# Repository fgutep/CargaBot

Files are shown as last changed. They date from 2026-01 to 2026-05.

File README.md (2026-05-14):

# CargaBot - Open Source ROS2 Forklift Platform

> **This is an active development project** - Originally started as a TurtleBot Burger clone, this project has evolved into a four-level forklift (montacargas) robot designed for object classification and manipulation.

An open-source, differential drive forklift robot designed to identify, pick up, and classify colored cubes (green, red, blue) using computer vision. By transitioning from a standard mobile base to a forklift architecture, CargaBot provides superior mechanical stability and simplified vertical positioning compared to traditional multi-degree-of-freedom robotic arms.

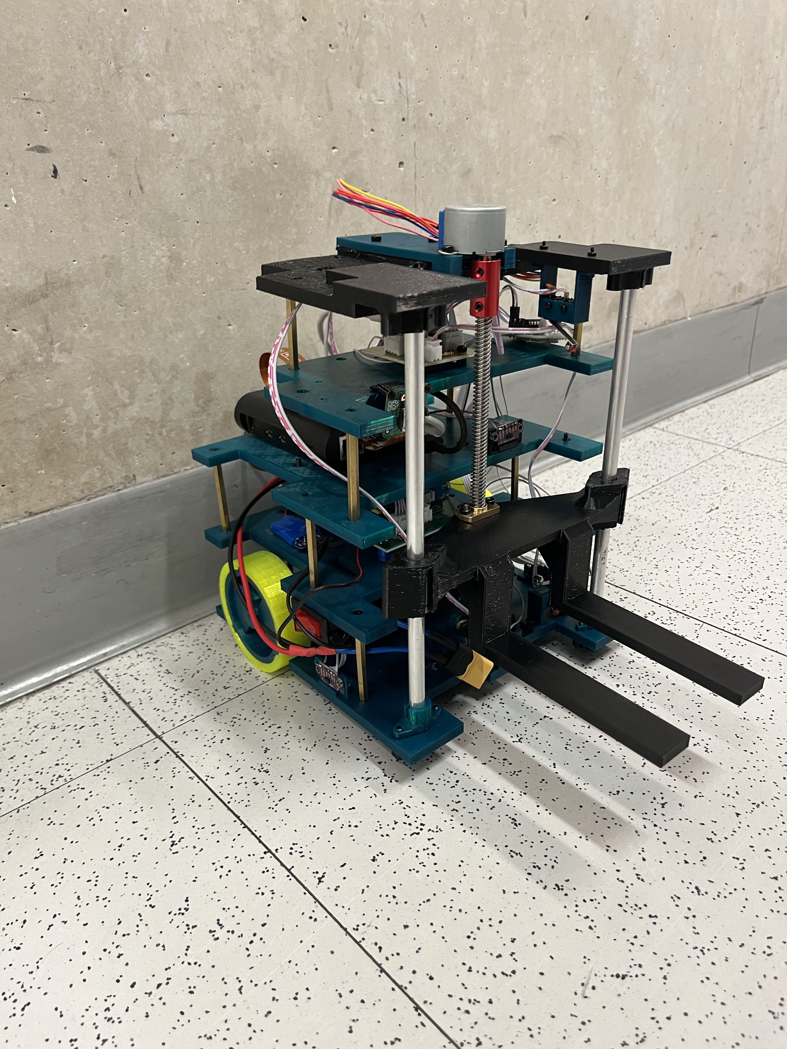
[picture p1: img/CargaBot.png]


## Project Goals

- **Accessible**: Built using affordable components like the Raspberry Pi 5, ESP32 microcontrollers, and fully 3D-printable parts.
- **Educational**: A hands-on platform for learning ROS2, computer vision (YOLOv8), embedded systems, and robot kinematics.
- **Object Manipulation**: Features a custom-built elevator mechanism specifically designed for picking up and stacking objects in a laboratory environment.
- **Distributed Processing**: Utilizes remote PC processing for heavy computer vision tasks to maintain real-time operational efficiency on the robot itself.

## Bill of Materials

### Electronics
- **Main Computer**: Raspberry Pi 5 (8GB) - Serves as the primary system processor and runs the ROS2 middleware.
- **Motion Controller**: ESP32-S3 (Dual-core, 240 MHz) - Manages the wheel odometry and traction bridge.
- **Lift & Sensor Controller**: Custom Waveshare ESP32-S3 Zero PCB - Handles $I^{2}C$ multiplexing and elevator control signals.
- **Sensors**: 5x VL53L0X Time-of-Flight sensors - Four provide lateral obstacle avoidance, while the fifth measures the elevator's height.
- **Vision**: Raspberry Pi Camera Module (5 MP, CSI interface) - Oriented downward to capture objects for the vision model.
- **Motors (Traction)**: 2x DC motors with integrated encoders for precise odometry.
- **Motor (Lift)**: 5V Stepper motor for driving the vertical elevator mechanism.
- **Drivers**: Two DRV8833 drivers (configured in parallel to handle higher current) for traction, and a dedicated 5V stepper driver for the lift.

### Mechanical
- **Chassis**: Custom 4-level 3D-printed PLA structure connected by structural support rods for dynamic rigidity.
- **Elevator System**: Driven by a T8 4-start lead screw, supported by upper and lower mechanical limit switches (end-stops) for safe positioning.
- **Wheels**: Custom PLA-printed wheels equipped with TPU treads to significantly improve traction and reduce slipping.

## Key Features & Architecture

### Hardware: The 4-Level Design
- **Level 1 (Base)**: Houses the traction motors, the TPU-treaded wheels, and four VL53L0X ToF sensors pointing forward, backward, left, and right for obstacle avoidance.
- **Level 2 (Electronic Control)**: Contains the main ESP32-S3 board, the parallel DRV8833 motor drivers, and decoupling capacitors.
- **Level 3 (Computation)**: Holds the Raspberry Pi 5 and a vertically positioned fifth VL53L0X sensor used to continuously track the elevator's height without signal interference.
- **Level 4 (Elevator System)**: Accommodates the Pi Camera, the 5V stepper motor driver, and the custom Waveshare ESP32-S3 Zero PCB used for the $I^{2}C$ multiplexing.

### Software
- **ROS2 Middleware**: Relies on a full ROS2 communication suite managing synchronized, distributed nodes.
- **Dual Serial Bridges**: Operates two independent communication bridges; one dedicated to wheel odometry/positioning, and a new "Zero" bridge for exposing the five ToF sensors and the lift state.
- **Distributed YOLOv8 Vision**: Local YOLOv8 inference saturated the Raspberry Pi 5 CPU (reaching 97%), making it impossible to run other nodes simultaneously. To solve this, video is streamed continuously via GStreamer (RTSP protocol) to a desktop computer. The PC runs the YOLOv8 model in real-time and publishes the detection results (class, confidence, and coordinates) back to the robot via ROS2 messages.

## Known Issues & Future Improvements

- **Lift Speed**: The current 5V stepper motor provides precision but is very slow, taking approximately 90 seconds to elevate the platform 15 cm. A planned improvement is to replace this with a more powerful DC motor coupled with gears.
- **Low-Speed PID Control**: The traction PID control has a sensitive minimum PWM threshold and behaves abruptly at low speeds. Upgrading to higher-capacity drivers and further tuning is planned for future iterations.
- **Vision Latency**: While running inference on the PC's GPU is highly efficient, the RTSP video transmission introduces around 200 ms of latency. Future optimizations will explore video compression and hardware acceleration on the Pi 5 to reduce this delay.

## Repository Structure
*(Structure is currently being reorganized to accommodate the new dual-firmware and 4-level chassis files)*

## Getting Started
### Prerequisites
- 3D printer (PLA for chassis components, TPU for wheel treads).
- ROS2 installation (Humble recommended).
- A remote PC with a dedicated GPU for YOLOv8 processing.

*Detailed wiring and build instructions for the 4-level chassis coming soon!*

## Contributing
We welcome contributions! Please open an issue or pull request if you'd like to contribute.

## License
This project is open-source and available under the [MIT License](LICENSE).

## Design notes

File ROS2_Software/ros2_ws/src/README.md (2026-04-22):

# TurtleBot ROS2 Lab 1

Proyecto de control y seguimiento de trayectoria de TurtleBot usando ROS2 Humble.

## Descripción

Este proyecto implementa tres nodos de ROS2:
- **turtle_bot_teleop**: Control manual del robot mediante teclado (WASD)
- **turtle_bot_interface**: Interfaz gráfica para visualizar trayectoria y gestionar grabaciones
- **turtle_bot_player**: Reproducción de trayectorias grabadas

## Requisitos

- ROS2 Humble  (pues a la maldita sea con jazzy tambien)
- Python 3.10+
- CoppeliaSim (para simulación)
- Librerías: matplotlib, tkinter

## Instalación
```bash
# Clonar el repositorio
cd ~/ros2_ws/src
git clone https://github.com/TU_USUARIO/turtlebot-ros2-lab1.git

# Instalar dependencias
pip3 install matplotlib --break-system-packages
sudo apt install python3-tk

# Compilar
cd ~/ros2_ws
colcon build
source install/setup.bash
```

## Uso

### Terminal 1: Interfaz gráfica
```bash
ros2 run lab1_py_pkg turtle_bot_interface
```

### Terminal 2: Control por teclado
```bash
ros2 run lab1_py_pkg turtle_bot_teleop
```

### Terminal 3: Reproductor (opcional)
```bash
ros2 run lab1_py_pkg turtle_bot_player
```

## Estructura del Proyecto
```
turtlebot_lab1_project/
├── lab1_msgs/              # Mensajes y servicios personalizados
│   ├── msg/
│   │   └── RobotAction.msg
│   └── srv/
│       └── PlayRecording.srv
└── lab1_py_pkg/            # Nodos de Python
    ├── turtle_bot_teleop.py
    ├── turtle_bot_interface.py
    └── turtle_bot_player.py
```

## Características

- ✅ Control del robot con WASD
- ✅ Visualización de trayectoria en tiempo real
- ✅ Grabación de secuencia de acciones
- ✅ Reproducción de trayectorias grabadas
- ✅ Exportación de gráficas (PNG, PDF, SVG)
- ✅ Mensajes y servicios personalizados

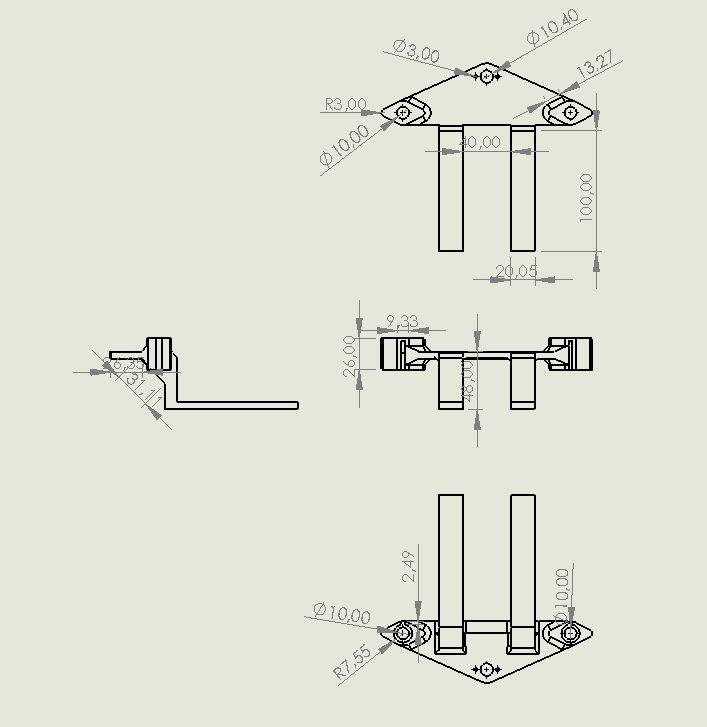
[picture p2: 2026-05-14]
CAD/PLANOS/Plano_soporte_elevador.png

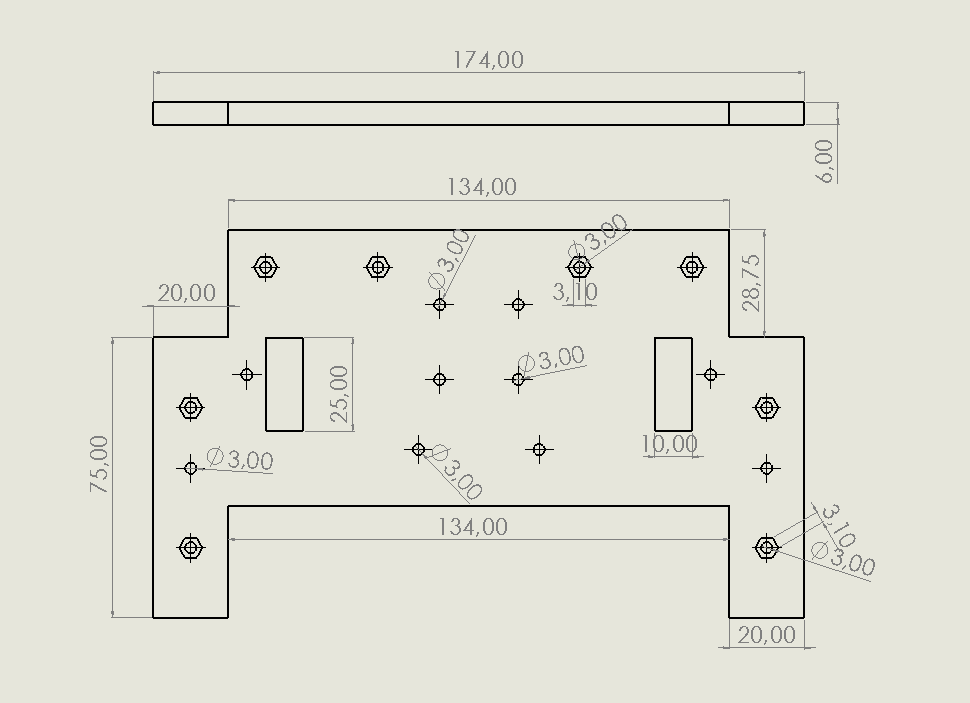
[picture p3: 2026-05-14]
CAD/PLANOS/Plano_piso4.png

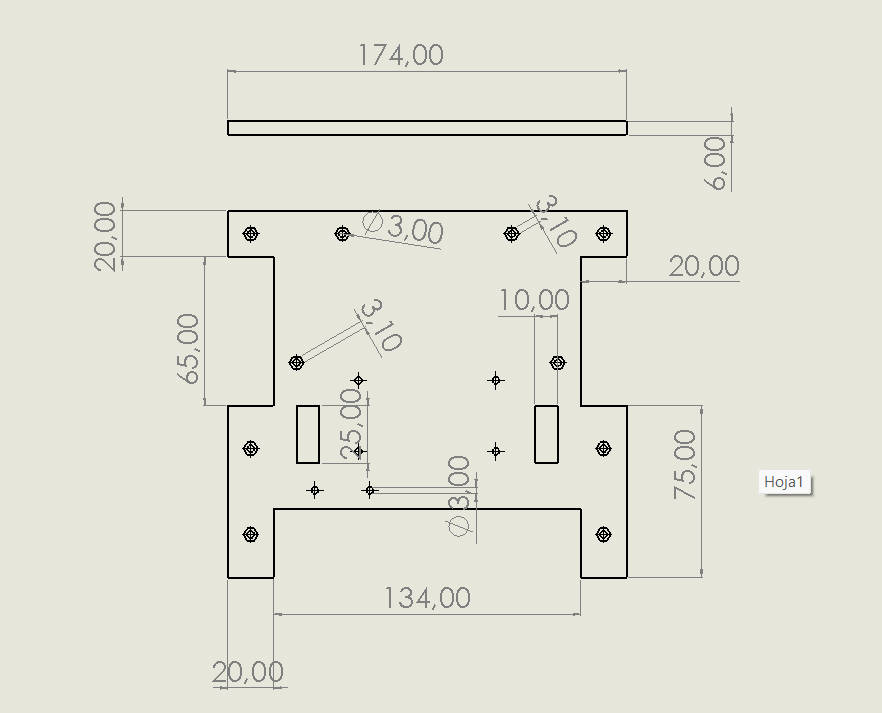
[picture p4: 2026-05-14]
CAD/PLANOS/Plano_piso2.png

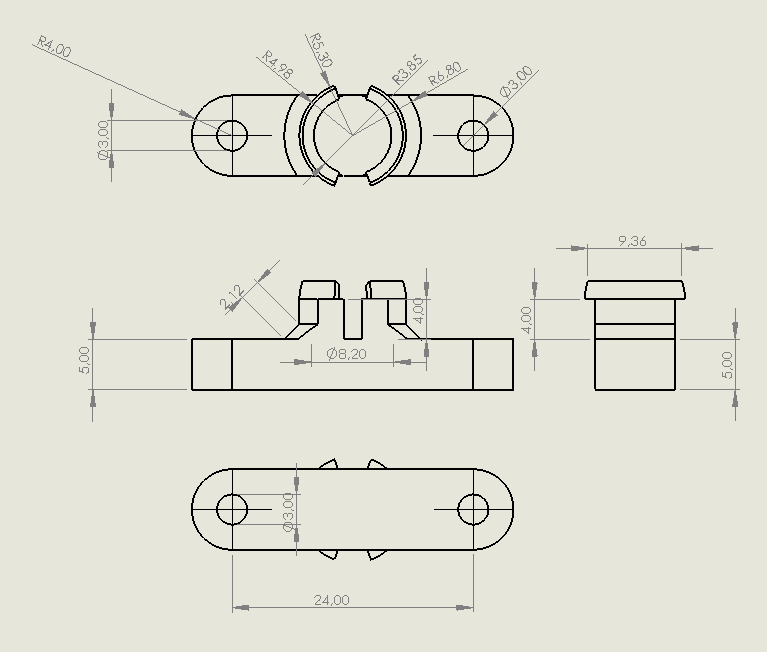
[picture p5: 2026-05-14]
CAD/PLANOS/Soporte_rueda_loca.png

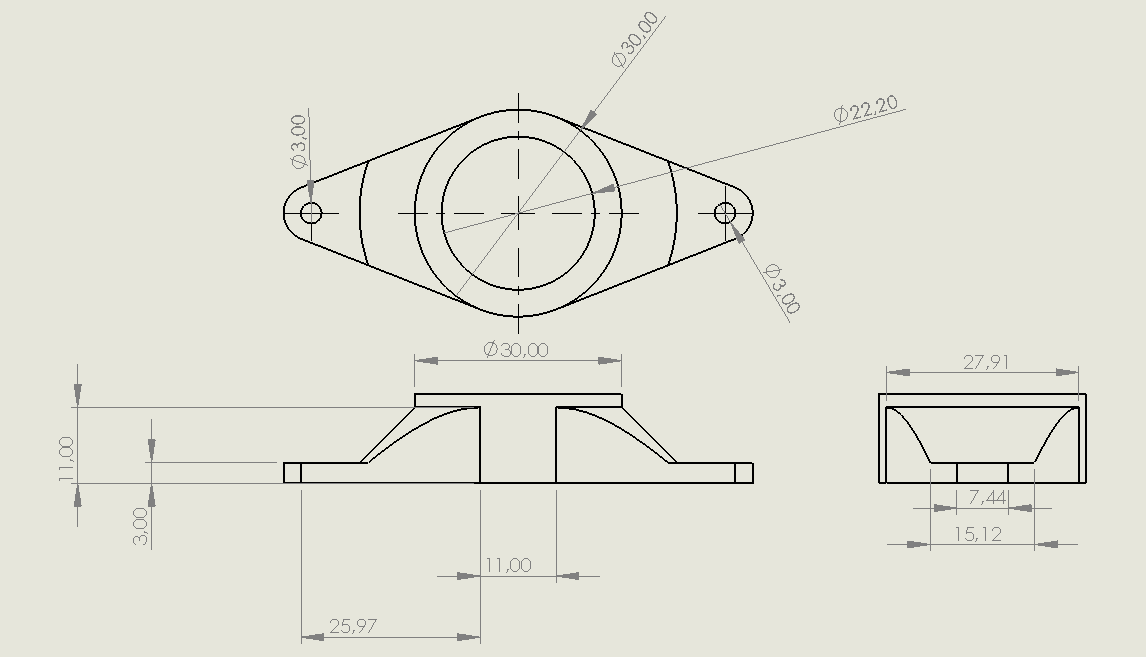
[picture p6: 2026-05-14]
CAD/PLANOS/Soporte_lead_screw.png

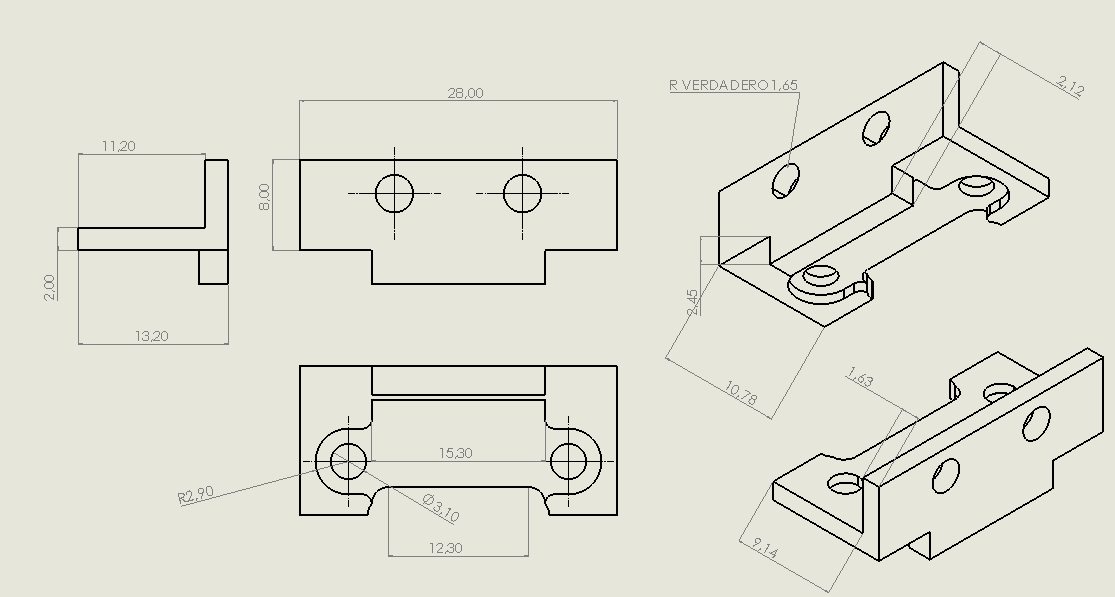
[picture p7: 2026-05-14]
CAD/PLANOS/Plano_bracket_tof.png

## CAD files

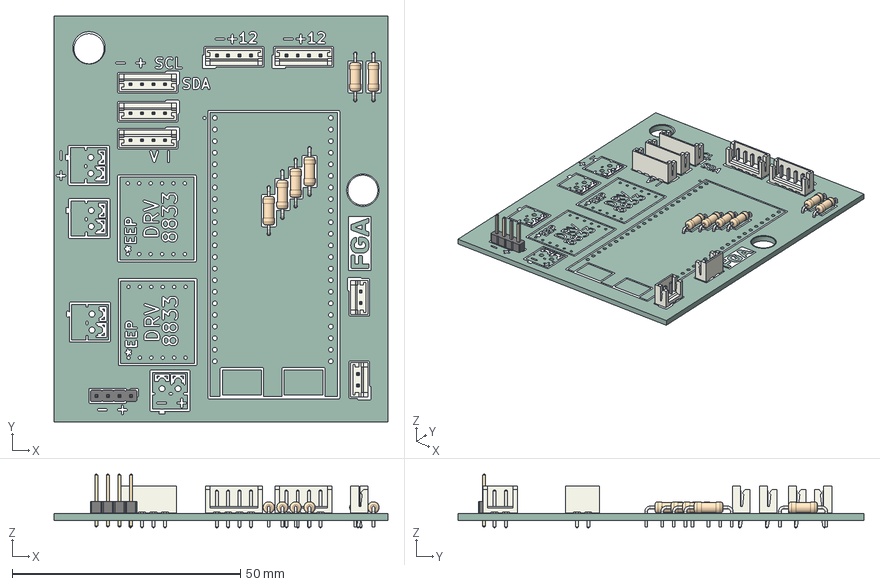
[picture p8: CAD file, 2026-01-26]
pcb/TurtleBot_PCB/TurtleBot_PCB.step
73.2 x 88.9 x 11.7 mm
JST_EH_B2B-EH-A_1x02_P2.50mm_Vertical x 2
PinHeader_1x04_P2.54mm_Vertical
JST_EH_B4B-EH-A_1x04_P2.50mm_Vertical x 5
R_Axial_DIN0207_L6.3mm_D2.5mm_P10.16mm_Horizontal x 6
TurtleBot_PCB_silkscreen
TurtleBot_PCB_PCB

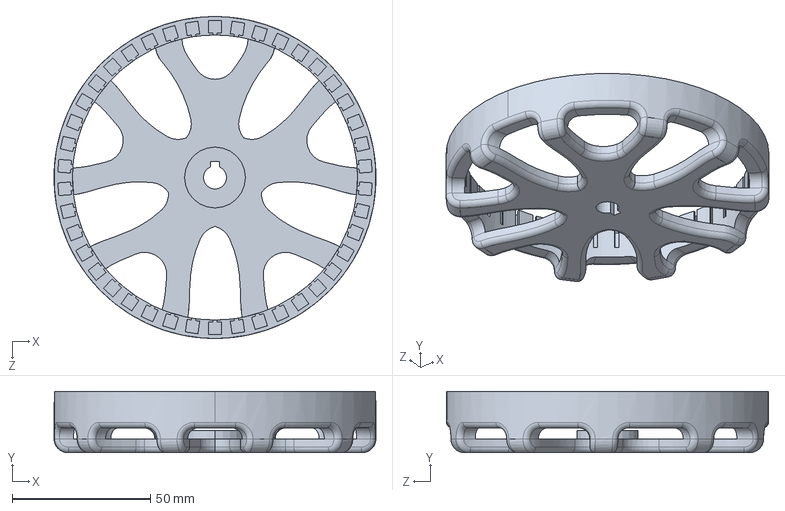
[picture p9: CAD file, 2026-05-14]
CAD/Rotor_23to1.step.SLDPRT
116.4 x 22.2 x 116.4 mm

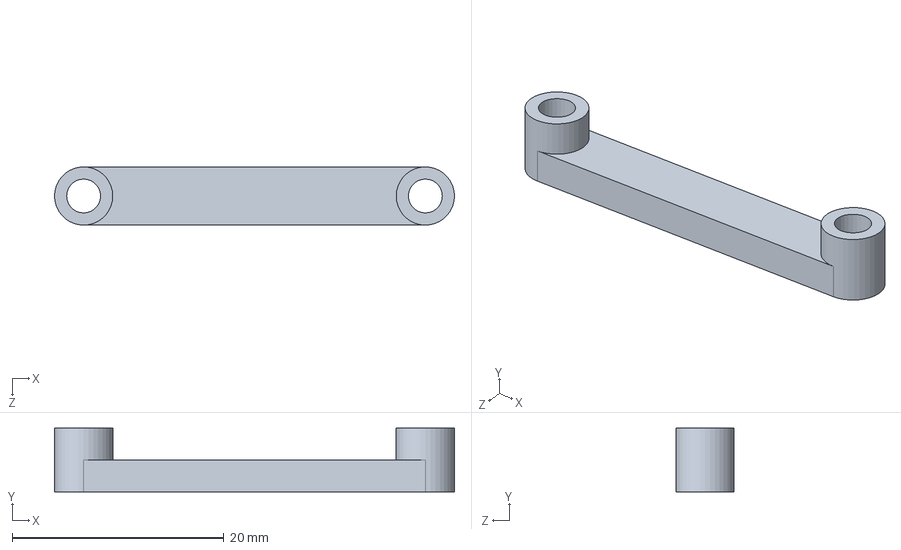
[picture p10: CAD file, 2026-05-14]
CAD/Soporte_pcb_steper.SLDPRT
37.8 x 6.00 x 5.50 mm

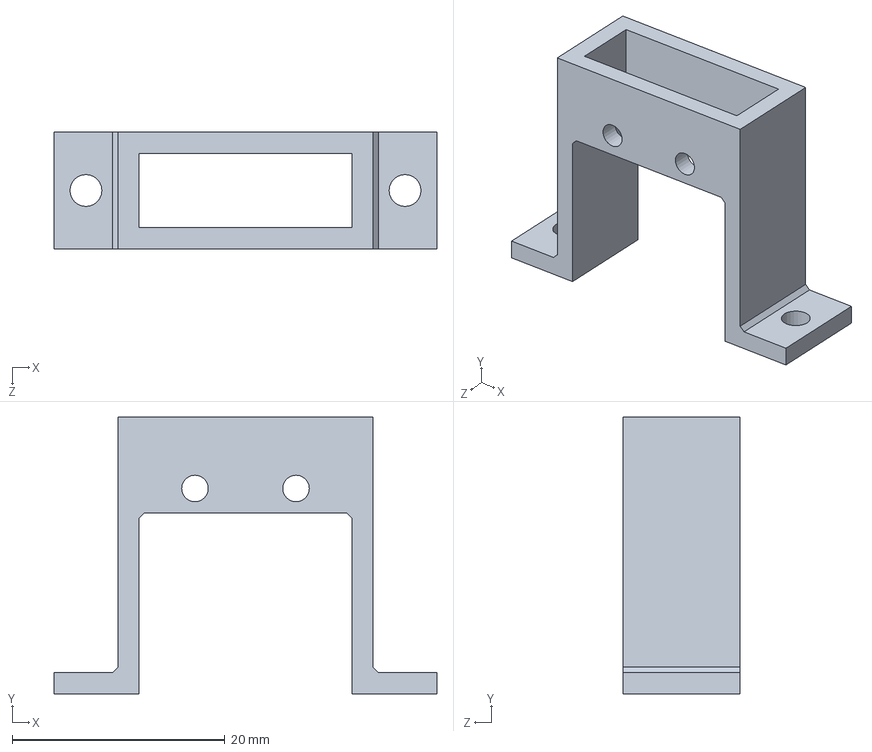
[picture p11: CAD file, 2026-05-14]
CAD/Soporte_fin_carrera_arriba.SLDPRT
36.0 x 26.0 x 11.0 mm

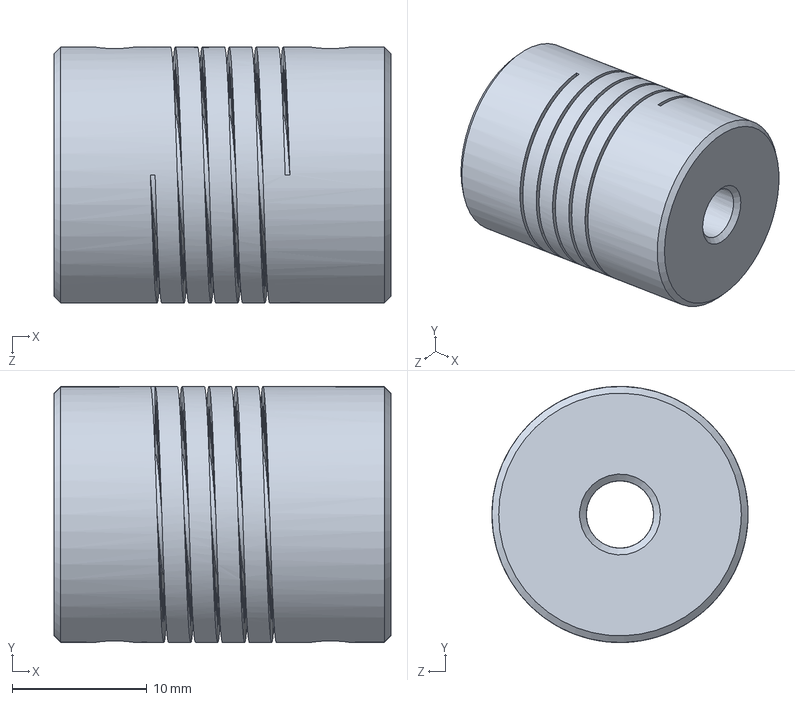
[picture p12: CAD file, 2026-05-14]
CAD/Flexible Shaft Coupler 5x8mm.SLDPRT
25.0 x 19.0 x 19.0 mm

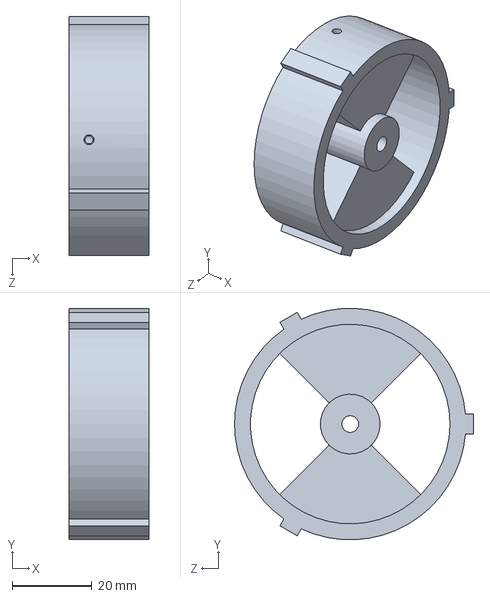
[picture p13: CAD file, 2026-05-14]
CAD/rueda.SLDPRT
20.0 x 58.0 x 59.9 mm

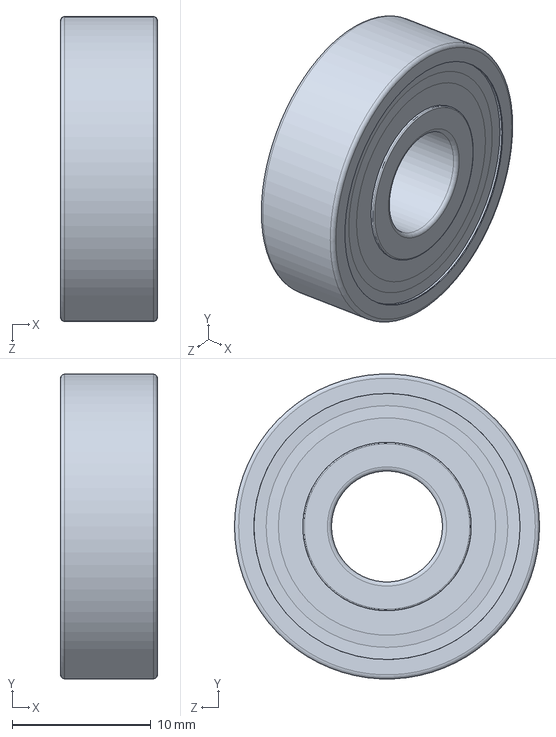
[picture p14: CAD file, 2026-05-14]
CAD/SKF_608-2ZZ.SLDPRT
7.00 x 22.0 x 22.0 mm

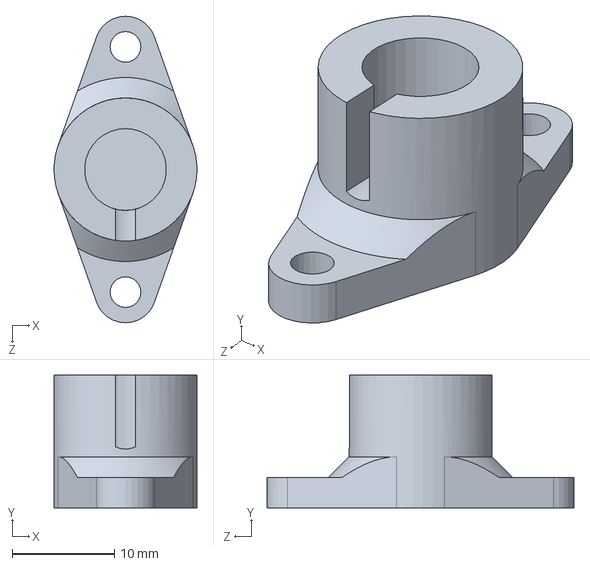
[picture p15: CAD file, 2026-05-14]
CAD/Apoyo_varilla.SLDPRT
14.0 x 13.0 x 30.0 mm

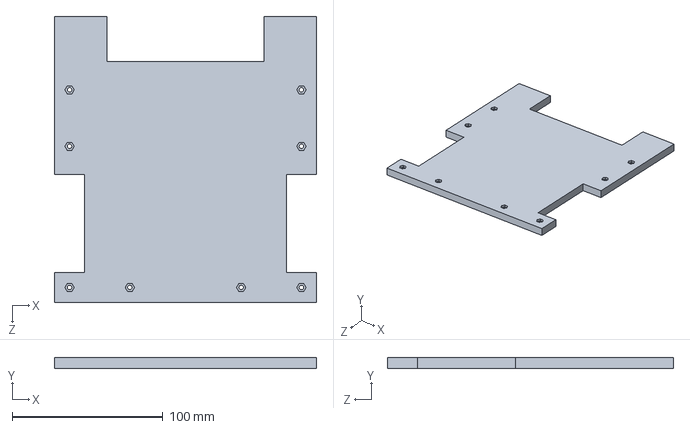
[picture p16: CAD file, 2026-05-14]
CAD/Base.SLDPRT
174.0 x 7.00 x 190.0 mm

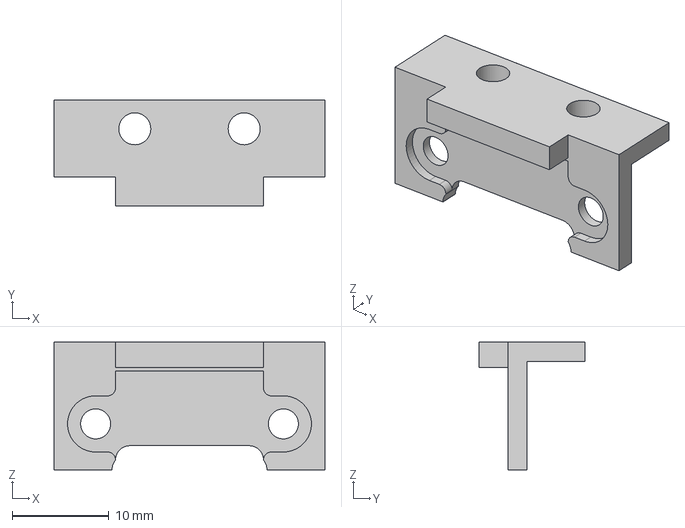
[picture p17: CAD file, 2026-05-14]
CAD/Bracket_VLX_ToF.step
28.0 x 11.0 x 13.2 mm

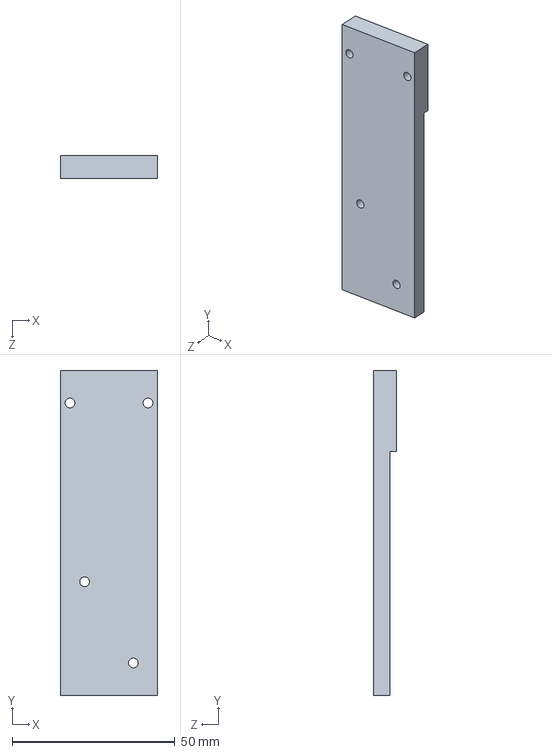
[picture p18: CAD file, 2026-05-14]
CAD/Soporte_arriba.SLDPRT
30.0 x 100.0 x 7.00 mm

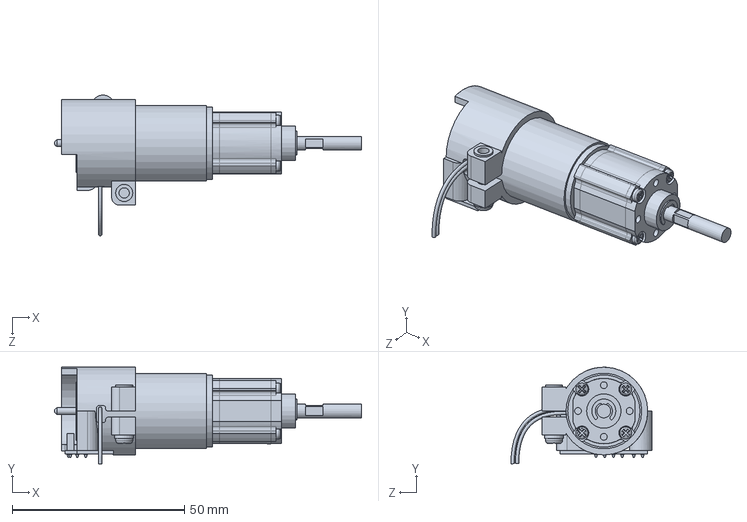
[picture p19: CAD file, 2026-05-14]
CAD/Namiki with Encoder.SLDPRT
89.2 x 28.1 x 41.0 mm

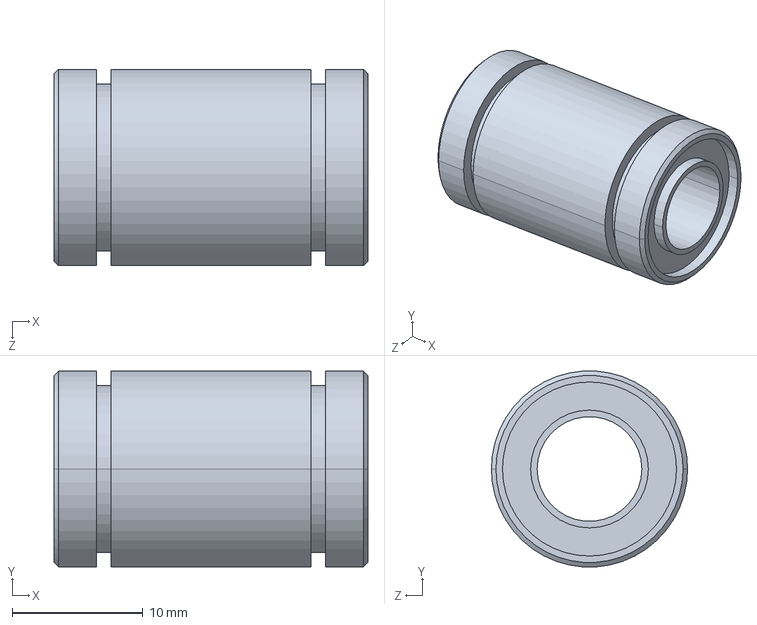
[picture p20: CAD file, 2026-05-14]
CAD/LM8UU.SLDPRT
24.0 x 15.0 x 15.0 mm

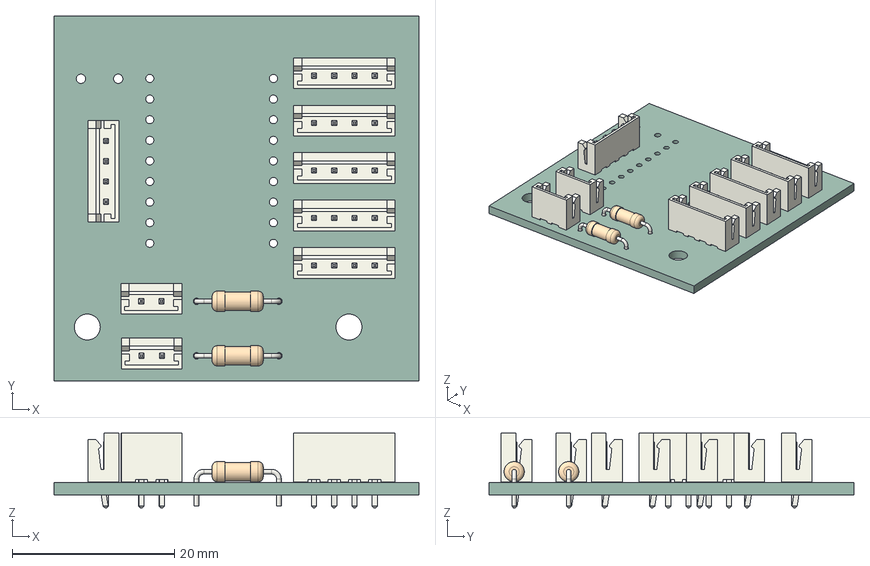
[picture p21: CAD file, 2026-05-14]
CAD/PCB_Sens_Elev.step
45.0 x 45.0 x 9.20 mm
JST_EH_B2B-EH-A_1x02_P2.50mm_Vertical x 2
R_Axial_DIN0207_L6.3mm_D2.5mm_P10.16mm_Horizontal x 2
JST_EH_B4B-EH-A_1x04_P2.50mm_Vertical x 6
PCB_Sens_Elev_PCB

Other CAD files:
CAD/Ensamblaje General.SLDASM
CAD/Soporte_rueda_loca.SLDPRT
CAD/Pieza2.SLDPRT
CAD/Soporte_fin_carrera.SLDPRT
CAD/28BYJ-48_Stepper.SLDPRT
CAD/Bola_loca.SLDPRT
CAD/Bracket_VLX_ToF.SLDPRT
CAD/Camera Moudule 3 v8.step
CAD/LeadScrew 8mm x 2mmPitch.SLDPRT
CAD/LeadScrew Nut 8mm x 2mmPitch.SLDPRT
CAD/NO-NC Bump Switch.step
CAD/PISO2.SLDPRT
CAD/PISO4.SLDPRT
CAD/PISO4_new.SLDPRT
CAD/SOPORTE BATERIA.SLDPRT
CAD/SOPORTE PCB.SLDPRT
CAD/SOPORTE RASBERRY PI.SLDPRT
CAD/Soporte Motor.SLDPRT
CAD/Soporte_arriba_fin_carrera.SLDPRT
CAD/Soporte_camara.SLDPRT
CAD/Soporte_rueda_loca.SLDDRW
CAD/Standoff.SLDPRT
CAD/TAPA SOPORTE BATERIA.SLDPRT
CAD/TurtleBot_PCB.SLDASM
CAD/TurtleBot_PCB.step
CAD/huella.SLDPRT
CAD/soporte_elevador.SLDPRT
CAD/soporte_lead_screw.SLDPRT
CAD/soporte_linear_bearing.SLDPRT
CAD/varilla_guia.SLDPRT

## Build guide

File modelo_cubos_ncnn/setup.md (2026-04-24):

# Setup Guide for YOLO NCNN on Raspberry Pi (Ubuntu)

This guide explains how to set up the environment to run the `test_ncnn.py` script on a Raspberry Pi using Ubuntu.

## 1. Install System Dependencies
Before creating the virtual environment, ensure you have the necessary system packages for Python development and OpenCV:

```bash
sudo apt update
sudo apt install -y python3-venv python3-pip libgl1-mesa-glx libglib2.0-0
```

## 2. Create a Virtual Environment
Ubuntu on Raspberry Pi often restricts global `pip` installs (PEP 668). We use a virtual environment to manage dependencies safely:

```bash
# Navigate to the project directory
cd ~/Downloads/modelo_cubos_ncnn

# Create the virtual environment
python3 -m venv .venv

# Activate the virtual environment
source .venv/bin/activate
```

## 3. Install Python Packages
Once the environment is active, install the required libraries:

```bash
pip install --upgrade pip
pip install ultralytics ncnn opencv-python
```

## 4. Running the Script
Always ensure the virtual environment is active before running the script:

```bash
# Activate (if not already active)
source .venv/bin/activate

# Run the test script
python3 test_ncnn.py
```

## Troubleshooting
- **Camera Access:** If the webcam doesn't open, ensure your user has permission to access video devices: `sudo usermod -aG video $USER` (re-login required).
- **Performance:** NCNN is optimized for ARM CPUs like the one in the Raspberry Pi, but performance will vary depending on the model size and Pi version.

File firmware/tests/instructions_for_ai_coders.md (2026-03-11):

# AI Coder Guidelines: ESP32 Differential Drive Motor Base

## 1. System Architecture
* **Microcontroller:** ESP32 (S3/S2/C3 variants).
* **Motor Drivers:** TWO DRV8833 drivers.
* **Configuration:** Paralleled channels (IN1 tied to IN3, IN2 tied to IN4) to double current capacity.
* **Encoders:** Quadrature Hall-effect encoders (3840 CPR).
* **Kinematics:** Differential drive (motors are physically mirrored).

## 2. Pin Mapping Reference
Ensure all generated code strictly adheres to these exact GPIO assignments:

| Component | Pin Function | ESP32 GPIO | Notes |
| :--- | :--- | :--- | :--- |
| **Motor A** | IN1 & IN3 | 9 | - |
| **Motor A** | IN2 & IN4 | 8 | - |
| **Motor B** | IN1 & IN3 | 11 | - |
| **Motor B** | IN2 & IN4 | 10 | - |
| **Driver Ctrl** | EEP (Sleep) | 12 | **MUST** be driven `HIGH` in `setup()` to wake drivers. |
| **Encoder A** | Phase A | 4 | Requires `INPUT_PULLUP` and hardware interrupts. |
| **Encoder A** | Phase B | 5 | Requires `INPUT_PULLUP` and hardware interrupts. |
| **Encoder B** | Phase A | 6 | Requires `INPUT_PULLUP` and hardware interrupts. |
| **Encoder B** | Phase B | 7 | Requires `INPUT_PULLUP` and hardware interrupts. |

## 3. Core Logic Rules & "Gotchas"
When generating C++ (Arduino framework) code for this system, adhere to the following rules:

### A. Driver Enable/Sleep (EEP)
* The EEP pin (`GPIO 12`) controls both DRV8833 chips. If not set to `OUTPUT` and written `HIGH`, the motors will not spin regardless of input signals. 

### B. Differential Drive Inversion
* Because the motors face opposite directions on the chassis, applying identical forward logic to both will cause the robot to spin in place.
* **Software Rule:** Motor B's directional logic must always be inverted relative to Motor A in the motor control function.
    * *Forward A:* IN1/3 = HIGH, IN2/4 = LOW
    * *Forward B:* IN1/3 = LOW, IN2/4 = HIGH

### C. Encoder Handling
* Use a lookup table (`QDEC_LUT`) for rapid, noise-resistant quadrature decoding inside `IRAM_ATTR` interrupt service routines (ISRs).
* Disable interrupts briefly (`noInterrupts()`) when copying volatile encoder counts to local variables in the main loop to prevent race conditions.

### D. PWM Implementation (ESP32 API v3.x)
* Use the modern ESP32 API.
* Do **not** use `ledcSetup` or `ledcAttachPin`.
* Use `ledcAttach(pin, frequency, resolution)` in `setup()`.
* Use `ledcWrite(pin, duty_cycle)` in the control loops.

## 4. Output Formatting Directives
* Keep all generated code and explanations strictly concise. 
* Avoid unnecessary comments; only document complex logic or non-standard API usage.

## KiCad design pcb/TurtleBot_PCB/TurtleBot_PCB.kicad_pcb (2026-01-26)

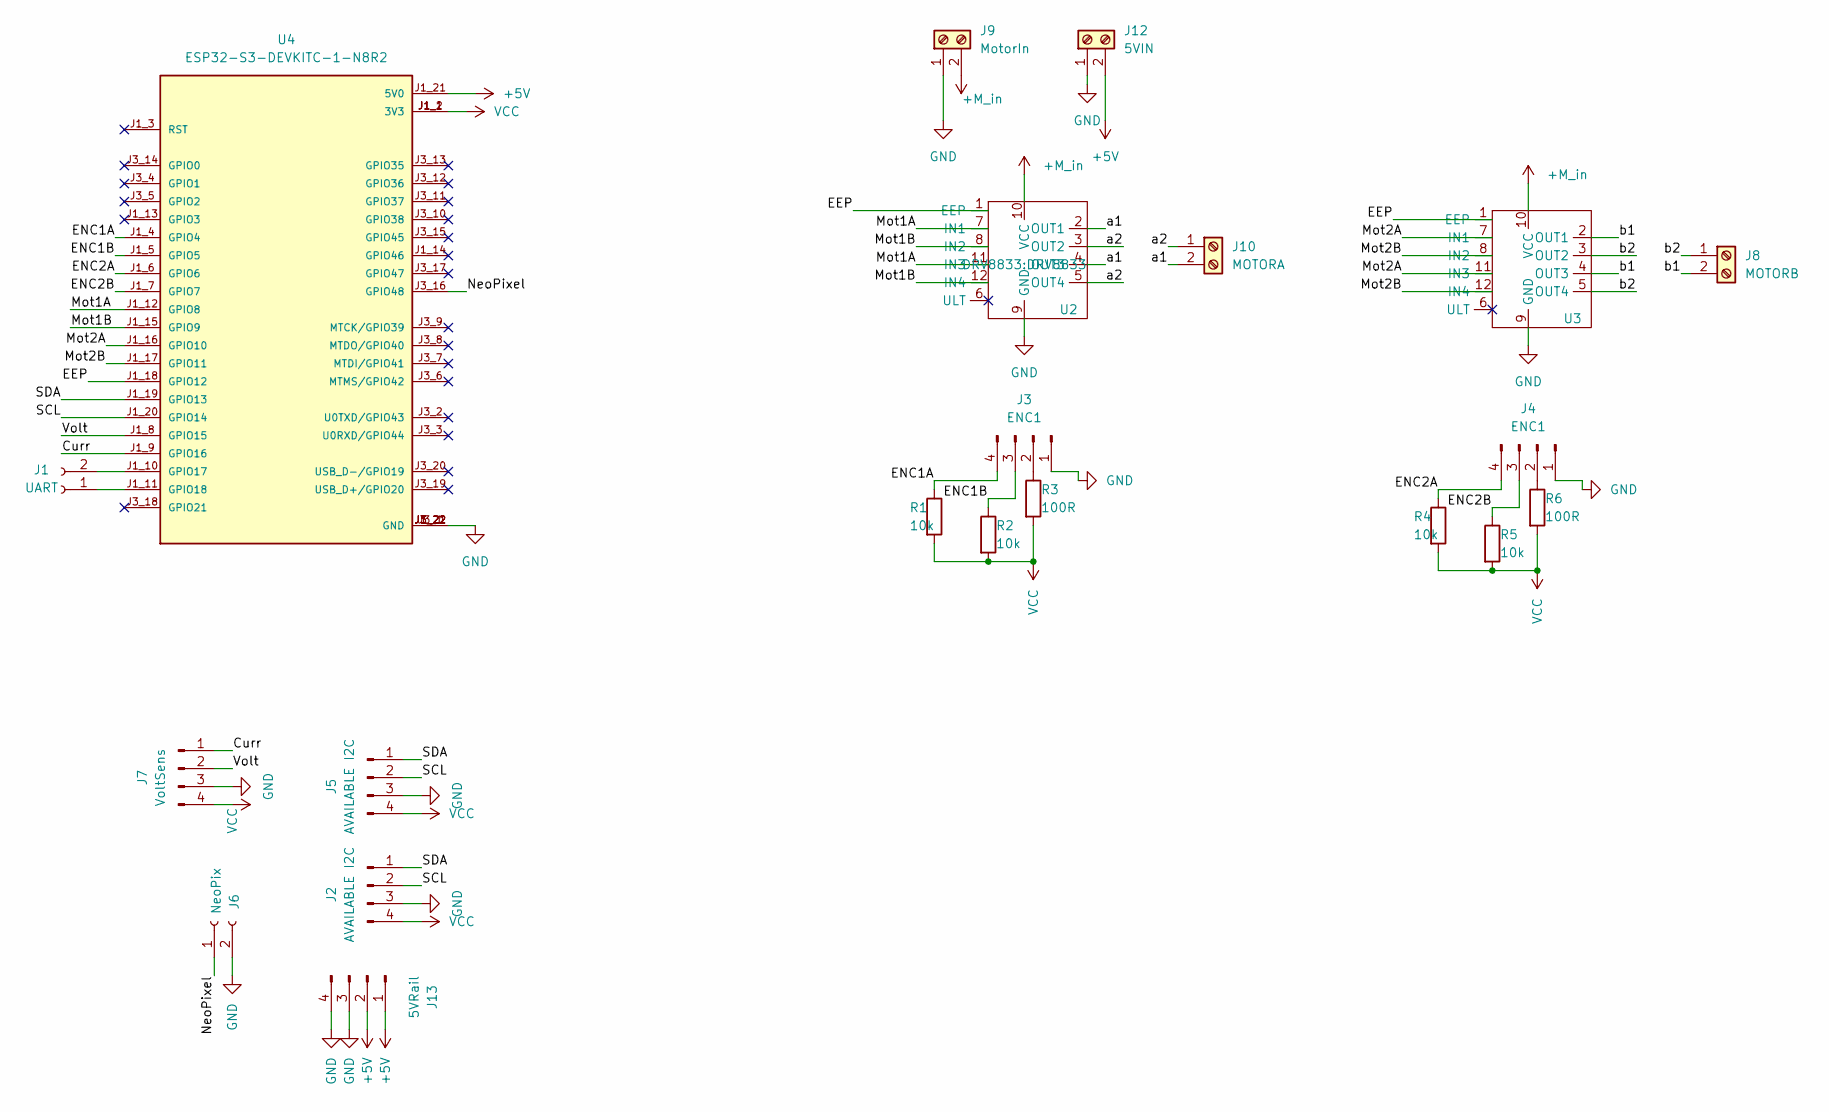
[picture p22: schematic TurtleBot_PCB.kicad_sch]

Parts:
J1: UART; JST_EH_B2B-EH-A_1x02_P2.50mm_Vertical
J2, J5: AVAILABLE I2C; JST_EH_B4B-EH-A_1x04_P2.50mm_Vertical
J3, J4: ENC1; JST_EH_B4B-EH-A_1x04_P2.50mm_Vertical
J6: NeoPix; JST_EH_B2B-EH-A_1x02_P2.50mm_Vertical
J7: VoltSens; JST_EH_B4B-EH-A_1x04_P2.50mm_Vertical
J8: MOTORB; TerminalBlock_4Ucon_1x02_P3.50mm_Vertical
J9: MotorIn; TerminalBlock_4Ucon_1x02_P3.50mm_Vertical
J10: MOTORA; TerminalBlock_4Ucon_1x02_P3.50mm_Vertical
J12: 5VIN; TerminalBlock_4Ucon_1x02_P3.50mm_Vertical
J13: 5VRail; PinHeader_1x04_P2.54mm_Vertical
R1, R2, R4, R5: 10k; R_Axial_DIN0207_L6.3mm_D2.5mm_P10.16mm_Horizontal
R3, R6: 100R; R_Axial_DIN0207_L6.3mm_D2.5mm_P10.16mm_Horizontal
U2, U3: DRV8833
U4: ESP32-S3-DEVKITC-1-N8R2; PARTREV V1

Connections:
+5V: J12.2, J13.1, J13.2, U4.J1_21 (5V0)
+M_in: J9.2, U2.10 (VCC), U3.10 (VCC)
/Curr: J7.1, U4.J1_9 (GPIO16)
/EEP: U2.1 (EEP), U3.1 (EEP), U4.J1_18 (GPIO12)
/ENC1A: J3.4, R1.1, U4.J1_4 (GPIO4)
/ENC1B: J3.3, R2.1, U4.J1_5 (GPIO5)
/ENC2A: J4.4, R4.1, U4.J1_6 (GPIO6)
/ENC2B: J4.3, R5.1, U4.J1_7 (GPIO7)
/Mot1A: U2.7 (IN1), U2.11 (IN3), U4.J1_12 (GPIO8)
/Mot1B: U2.8 (IN2), U2.12 (IN4), U4.J1_15 (GPIO9)
/Mot2A: U3.7 (IN1), U3.11 (IN3), U4.J1_16 (GPIO10)
/Mot2B: U3.8 (IN2), U3.12 (IN4), U4.J1_17 (GPIO11)
/NeoPixel: J6.1, U4.J3_16 (GPIO48)
/SCL: J2.2, J5.2, U4.J1_20 (GPIO14)
/SDA: J2.1, J5.1, U4.J1_19 (GPIO13)
/Volt: J7.2, U4.J1_8 (GPIO15)
/a1: J10.2, U2.2 (OUT1), U2.4 (OUT3)
/a2: J10.1, U2.3 (OUT2), U2.5 (OUT4)
/b1: J8.2, U3.2 (OUT1), U3.4 (OUT3)
/b2: J8.1, U3.3 (OUT2), U3.5 (OUT4)
GND: J2.3, J3.1, J4.1, J5.3, J6.2, J7.3, J9.1, J12.1, J13.3, J13.4, U2.9 (GND), U3.9 (GND), U4.J1_22 (GND), U4.J3_1 (GND), U4.J3_21 (GND), U4.J3_22 (GND)
unnamed: J1.1, U4.J1_11 (GPIO18)
unnamed: J1.2, U4.J1_10 (GPIO17)
unnamed: J3.2, R3.1
unnamed: J4.2, R6.1
VCC: J2.4, J5.4, J7.4, R1.2, R2.2, R3.2, R4.2, R5.2, R6.2, U4.J1_1 (3V3), U4.J1_2 (3V3)

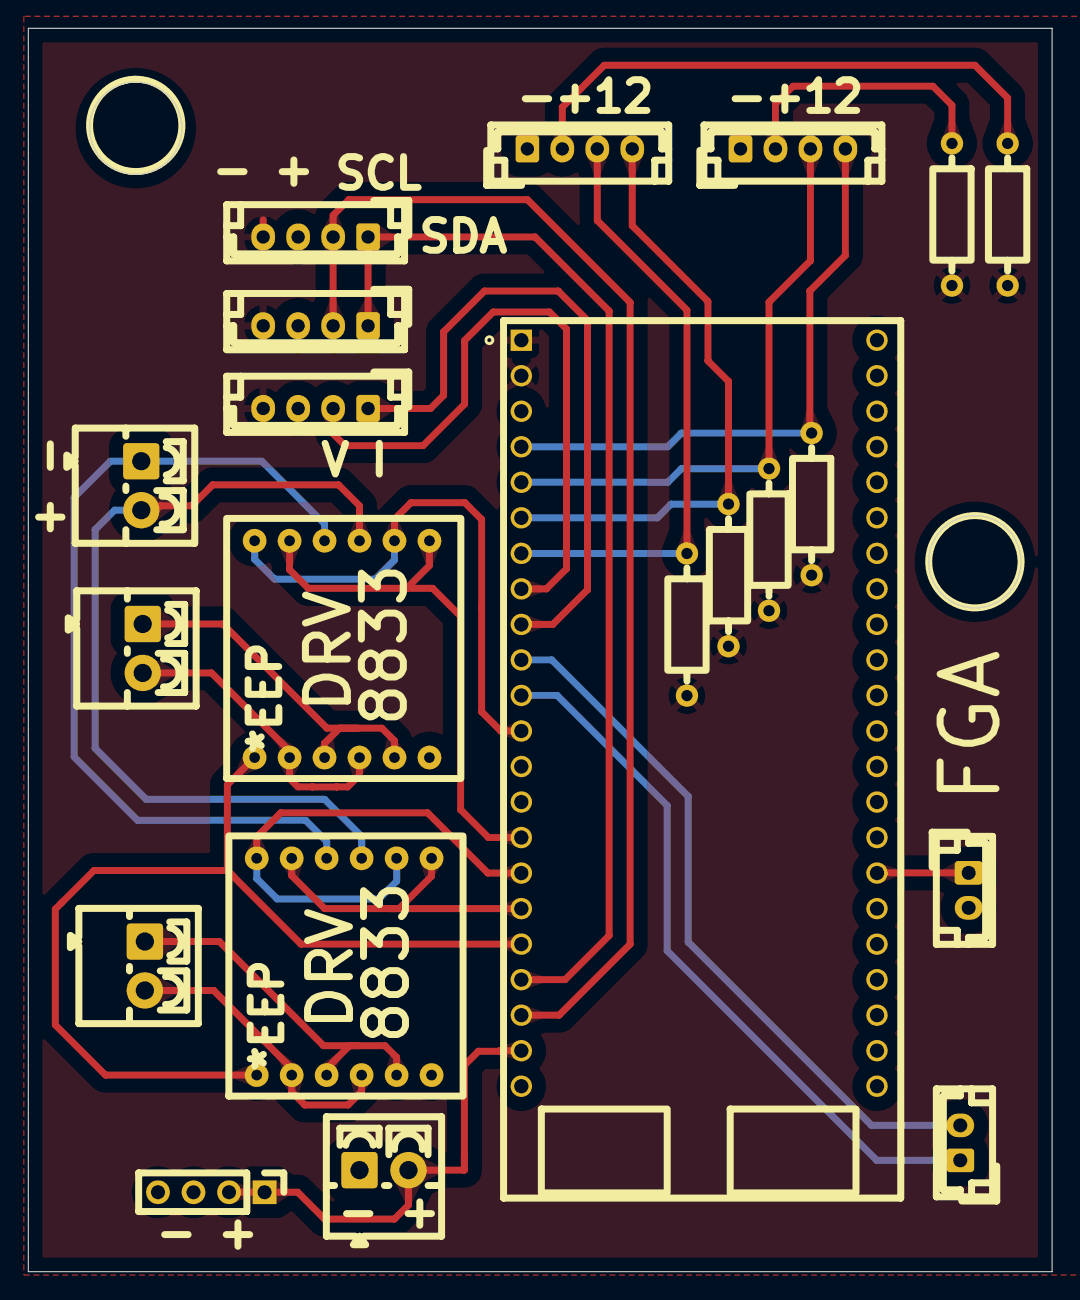
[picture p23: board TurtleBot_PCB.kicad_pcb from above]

Board: 2 copper layers, 73.2 x 88.9 mm, 21 parts (0 on the bottom side), 26 nets.

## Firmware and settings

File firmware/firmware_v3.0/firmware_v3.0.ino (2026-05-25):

#include <Arduino.h>
#include <ArduinoJson.h>
#include <Wire.h>
#include "I2Cdev.h"
#include "MPU6050_6Axis_MotionApps20.h"

// =====================================================================
// PINES DE HARDWARE
// =====================================================================
#define MOTOR_L_IN1 9
#define MOTOR_L_IN2 8
#define MOTOR_R_IN1 11
#define MOTOR_R_IN2 10
#define MOTOR_EEP   12

#define ENC_L_A 4
#define ENC_L_B 5
#define ENC_R_A 6
#define ENC_R_B 7

#define I2C_SDA_PIN 13
#define I2C_SCL_PIN 14

#define PWM_FREQ 20000
#define PWM_RES  8

// =====================================================================
// PARÁMETROS FÍSICOS
// =====================================================================
const float R      = 0.04f;
const float L      = 0.20f;
const float CPR_X4 = 426.67f;

// =====================================================================
// MPU6050
// =====================================================================
MPU6050 mpu;

bool     dmpReady  = false;
uint16_t packetSize;
uint8_t  fifoBuffer[64];

Quaternion  q;
VectorFloat gravity;
float       ypr[3];

// Yaw del DMP en radianes — referencia absoluta para odometría angular
float imu_yaw     = 0.0f;   // yaw actual [rad]
float imu_yaw_ref = 0.0f;   // yaw al momento del reset de odom
bool  imu_ok      = false;

// =====================================================================
// ENCODERS
// =====================================================================
volatile int32_t countL = 0, countR = 0;
uint8_t prevL = 0, prevR = 0;
static const int8_t QDEC_LUT[16] = {0,-1,1,0,1,0,0,-1,-1,0,0,1,0,1,-1,0};

// =====================================================================
// ESTADO DEL ROBOT
// =====================================================================
float odom_x = 0.0f, odom_y = 0.0f, odom_th = 0.0f;
float target_v = 0.0f, target_w = 0.0f;
float target_rpm_L = 0.0f, target_rpm_R = 0.0f;
float current_rpm_L = 0.0f, current_rpm_R = 0.0f;

// =====================================================================
// PID
// =====================================================================
float kpL = 1.35f, kiL = 2.5f,  kdL = 0.13f;
float kpR = 1.35f, kiR = 2.54f, kdR = 0.21f;

float integral_limit = 150.0f;
float d_filter_alpha = 0.6f;

float ffA_L = 0.71f, ffB_L = 30.0f;
float ffA_R = 0.71f, ffB_R = 30.0f;

float rpm_filter_alpha = 0.3f;
float filtered_rpm_L = 0.0f, filtered_rpm_R = 0.0f;

float err_sum_L = 0, last_err_L = 0, d_filtered_L = 0;
float err_sum_R = 0, last_err_R = 0, d_filtered_R = 0;
int   pwm_L = 0, pwm_R = 0;

// =====================================================================
// MODO DE OPERACIÓN
// =====================================================================
enum Mode { MODE_NORMAL, MODE_STEP, MODE_OPEN };
Mode mode = MODE_NORMAL;

float    step_rpm      = 0.0f;
uint32_t step_duration = 3000;
uint32_t step_start    = 0;
int      open_pwm_L    = 0, open_pwm_R = 0;

// =====================================================================
// TEMPORIZACIÓN
// =====================================================================
uint32_t last_time = 0;
const uint32_t LOOP_DT_MS = 50; // 20 Hz

// =====================================================================
// ISRs
// =====================================================================
void IRAM_ATTR isrL() {
  uint8_t curr = (digitalRead(ENC_L_B) << 1) | digitalRead(ENC_L_A);
  countL += QDEC_LUT[(prevL << 2) | curr];
  prevL = curr;
}
void IRAM_ATTR isrR() {
  uint8_t curr = (digitalRead(ENC_R_A) << 1) | digitalRead(ENC_R_B);
  countR += QDEC_LUT[(prevR << 2) | curr];
  prevR = curr;
}

// =====================================================================
// MOTORES
// =====================================================================
void setMotorPWM(int pwm_l, int pwm_r) {
  pwm_l = constrain(pwm_l, -255, 255);
  pwm_r = constrain(pwm_r, -255, 255);
  ledcWrite(MOTOR_L_IN1, pwm_l > 0 ?  pwm_l : 0);
  ledcWrite(MOTOR_L_IN2, pwm_l < 0 ? -pwm_l : 0);
  ledcWrite(MOTOR_R_IN1, pwm_r < 0 ? -pwm_r : 0);
  ledcWrite(MOTOR_R_IN2, pwm_r > 0 ?  pwm_r : 0);
}

void resetPID() {
  err_sum_L = err_sum_R = 0;
  last_err_L = last_err_R = 0;
  d_filtered_L = d_filtered_R = 0;
  pwm_L = pwm_R = 0;
}

void stopMotors() { setMotorPWM(0, 0); resetPID(); }

// =====================================================================
// PIDs
// =====================================================================
int computePID_L(float target, float measured, float dt) {
  float err    = target - measured;
  err_sum_L   += err * dt;
  err_sum_L    = constrain(err_sum_L, -integral_limit, integral_limit);
  float raw_d  = (err - last_err_L) / dt;
  d_filtered_L = d_filter_alpha * d_filtered_L + (1.0f - d_filter_alpha) * raw_d;
  last_err_L   = err;
  float ff  = (ffA_L * fabsf(target)) + ffB_L;
  float pid = (kpL * err) + (kiL * err_sum_L) + (kdL * d_filtered_L);
  return (int)constrain((target >= 0 ? 1 : -1) * ff + pid, -255, 255);
}

int computePID_R(float target, float measured, float dt) {
  float err    = target - measured;
  err_sum_R   += err * dt;
  err_sum_R    = constrain(err_sum_R, -integral_limit, integral_limit);
  float raw_d  = (err - last_err_R) / dt;
  d_filtered_R = d_filter_alpha * d_filtered_R + (1.0f - d_filter_alpha) * raw_d;
  last_err_R   = err;
  float ff  = (ffA_R * fabsf(target)) + ffB_R;
  float pid = (kpR * err) + (kiR * err_sum_R) + (kdR * d_filtered_R);
  return (int)constrain((target >= 0 ? 1 : -1) * ff + pid, -255, 255);
}

// =====================================================================
// IMU — lee DMP y actualiza imu_yaw
// Llamado cada loop, no bloqueante
// =====================================================================
void updateIMU() {
  if (!dmpReady) return;
  if (!mpu.dmpGetCurrentFIFOPacket(fifoBuffer)) return;

  mpu.dmpGetQuaternion(&q, fifoBuffer);
  mpu.dmpGetGravity(&gravity, &q);
  mpu.dmpGetYawPitchRoll(ypr, &q, &gravity);

  imu_yaw = ypr[0];  // radianes, referencia al norte magnético/gravedad
  imu_ok  = true;
}

// Ángulo de heading relativo al reset de odometría
// Normalizado a [-π, π]
float getOdomTh() {
  if (!imu_ok) return odom_th;  // fallback a encoders si IMU no responde
  float delta = imu_yaw - imu_yaw_ref;
  // Normalizar a [-π, π]
  while (delta >  M_PI) delta -= 2.0f * M_PI;
  while (delta < -M_PI) delta += 2.0f * M_PI;
  return delta;
}

// =====================================================================
// PARSEO JSON
// =====================================================================
void parseCommand(const char* buf) {
  StaticJsonDocument<384> doc;
  if (deserializeJson(doc, buf) != DeserializationError::Ok) return;

  if (doc.containsKey("v") && doc.containsKey("w")) {
    mode     = MODE_NORMAL;
    target_v = -(float)doc["v"];
    target_w = doc["w"];
    float v_l = target_v - (target_w * L / 2.0f);
    float v_r = target_v + (target_w * L / 2.0f);
    target_rpm_L = (v_l / (2.0f * PI * R)) * 60.0f;
    target_rpm_R = (v_r / (2.0f * PI * R)) * 60.0f;
  }

  if (doc.containsKey("kpL")) kpL = doc["kpL"];
  if (doc.containsKey("kiL")) kiL = doc["kiL"];
  if (doc.containsKey("kdL")) kdL = doc["kdL"];
  if (doc.containsKey("kpR")) kpR = doc["kpR"];
  if (doc.containsKey("kiR")) kiR = doc["kiR"];
  if (doc.containsKey("kdR")) kdR = doc["kdR"];
  if (doc.containsKey("il"))  integral_limit   = doc["il"];
  if (doc.containsKey("df"))  d_filter_alpha   = doc["df"];
  if (doc.containsKey("rf"))  rpm_filter_alpha = doc["rf"];
  if (doc.containsKey("ffAL")) ffA_L = doc["ffAL"];
  if (doc.containsKey("ffBL")) ffB_L = doc["ffBL"];
  if (doc.containsKey("ffAR")) ffA_R = doc["ffAR"];
  if (doc.containsKey("ffBR")) ffB_R = doc["ffBR"];

  if (doc.containsKey("step_rpm")) {
    mode          = MODE_STEP;
    step_rpm      = doc["step_rpm"];
    step_duration = doc.containsKey("step_ms") ? (uint32_t)doc["step_ms"] : 3000;
    step_start    = millis();
    const char* wheel = doc["step_wheel"] | "both";
    if      (strcmp(wheel, "L") == 0) { target_rpm_L = step_rpm; target_rpm_R = 0; }
    else if (strcmp(wheel, "R") == 0) { target_rpm_L = 0; target_rpm_R = step_rpm; }
    else                               { target_rpm_L = target_rpm_R = step_rpm; }
    resetPID();
  }

  if (doc.containsKey("open_l") || doc.containsKey("open_r")) {
    mode = MODE_OPEN;
    if (doc.containsKey("open_l")) open_pwm_L = (int)doc["open_l"];
    if (doc.containsKey("open_r")) open_pwm_R = (int)doc["open_r"];
  }

  if (doc.containsKey("stop")) {
    mode = MODE_NORMAL;
    target_v = target_w = 0;
    target_rpm_L = target_rpm_R = 0;
    stopMotors();
  }

  if (doc.containsKey("reset_odom")) {
    // Resetear posición XY a 0
    odom_x = odom_y = 0.0f;
    // Resetear heading: guardar yaw actual como nueva referencia
    imu_yaw_ref = imu_yaw;
    odom_th     = 0.0f;
  }
}

// =====================================================================
// SETUP
// =====================================================================
void setup() {
  Serial.begin(115200);

  // ── Motores ──
  ledcAttach(MOTOR_L_IN1, PWM_FREQ, PWM_RES);
  ledcAttach(MOTOR_L_IN2, PWM_FREQ, PWM_RES);
  ledcAttach(MOTOR_R_IN1, PWM_FREQ, PWM_RES);
  ledcAttach(MOTOR_R_IN2, PWM_FREQ, PWM_RES);
  pinMode(MOTOR_EEP, OUTPUT);
  digitalWrite(MOTOR_EEP, HIGH);

  // ── Encoders ──
  pinMode(ENC_L_A, INPUT_PULLUP); pinMode(ENC_L_B, INPUT_PULLUP);
  pinMode(ENC_R_A, INPUT_PULLUP); pinMode(ENC_R_B, INPUT_PULLUP);
  attachInterrupt(ENC_L_A, isrL, CHANGE); attachInterrupt(ENC_L_B, isrL, CHANGE);
  attachInterrupt(ENC_R_A, isrR, CHANGE); attachInterrupt(ENC_R_B, isrR, CHANGE);

  // ── IMU ──
  Wire.begin(I2C_SDA_PIN, I2C_SCL_PIN);
  Wire.setClock(400000);
  mpu.initialize();

  if (mpu.testConnection()) {
    uint8_t devStatus = mpu.dmpInitialize();
    if (devStatus == 0) {
      // Calibración automática — mantener el robot quieto durante el setup
      mpu.CalibrateAccel(6);
      mpu.CalibrateGyro(6);
      mpu.setDMPEnabled(true);
      dmpReady   = true;
      packetSize = mpu.dmpGetFIFOPacketSize();
    }
    // Si falla el DMP el robot sigue funcionando con encoders para th
  }

  last_time = millis();
}

// =====================================================================
// LOOP
// =====================================================================
void loop() {

  // ── Leer IMU (no bloqueante) ──
  updateIMU();

  // ── Leer serial ──
  static char rxBuf[384];
  static uint16_t rxIdx = 0;
  while (Serial.available()) {
    char c = Serial.read();
    if (c == '\n') {
      rxBuf[rxIdx] = 0;
      parseCommand(rxBuf);
      rxIdx = 0;
    } else if (rxIdx < 383) {
      rxBuf[rxIdx++] = c;
    }
  }

  uint32_t now = millis();
  if (now - last_time < LOOP_DT_MS) return;
  float dt = (now - last_time) / 1000.0f;
  last_time = now;

  // ── Encoders → RPM ──
  int32_t cL, cR;
  noInterrupts();
  cL = countL; countL = 0;
  cR = countR; countR = 0;
  interrupts();

  current_rpm_L = ((float(cL) / dt) / CPR_X4) * 60.0f;
  current_rpm_R = ((float(cR) / dt) / CPR_X4) * 60.0f;

  filtered_rpm_L = rpm_filter_alpha * current_rpm_L + (1.0f - rpm_filter_alpha) * filtered_rpm_L;
  filtered_rpm_R = rpm_filter_alpha * current_rpm_R + (1.0f - rpm_filter_alpha) * filtered_rpm_R;

  // ── Odometría ──
  // Distancia lineal: encoders (más precisos para traslación)
  float v_l_meas = (filtered_rpm_L / 60.0f) * (2.0f * PI * R);
  float v_r_meas = (filtered_rpm_R / 60.0f) * (2.0f * PI * R);
  float v_meas   = (v_r_meas + v_l_meas) / 2.0f;

  // Heading: IMU si disponible, encoders como fallback
  odom_th = getOdomTh();

  // Integración de posición XY con heading del IMU
  odom_x += v_meas * cos(odom_th) * dt;
  odom_y += v_meas * sin(odom_th) * dt;

  // ── Fin de escalón ──
  if (mode == MODE_STEP && (now - step_start > step_duration)) {
    mode = MODE_NORMAL;
    target_rpm_L = target_rpm_R = 0;
    stopMotors();
  }

  // ── Control ──
  if (mode == MODE_OPEN) {
    pwm_L = open_pwm_L;
    pwm_R = open_pwm_R;
    setMotorPWM(open_pwm_L, open_pwm_R);
  } else {
    pwm_L = (target_rpm_L == 0) ? 0 : computePID_L(target_rpm_L, filtered_rpm_L, dt);
    pwm_R = (target_rpm_R == 0) ? 0 : computePID_R(target_rpm_R, filtered_rpm_R, dt);

    if (target_rpm_L == 0) { err_sum_L = 0; d_filtered_L = 0; filtered_rpm_L = 0; }
    if (target_rpm_R == 0) { err_sum_R = 0; d_filtered_R = 0; filtered_rpm_R = 0; }

    setMotorPWM(pwm_L, pwm_R);
  }

  // ── Telemetría ──
  StaticJsonDocument<512> out;
  out["t"]    = now;
  out["rpmL"] = filtered_rpm_L;
  out["rpmR"] = filtered_rpm_R;
  out["rawL"] = current_rpm_L;
  out["rawR"] = current_rpm_R;
  out["tgtL"] = target_rpm_L;
  out["tgtR"] = target_rpm_R;
  out["pwmL"] = pwm_L;
  out["pwmR"] = pwm_R;
  out["x"]    = odom_x;
  out["y"]    = odom_y;
  out["th"]   = odom_th;
  out["yaw"]  = imu_yaw;          // yaw absoluto del IMU [rad]
  out["imu"]  = (int)imu_ok;      // 1 = IMU activo, 0 = fallback encoders
  out["mode"] = (int)mode;
  out["kpL"]  = kpL; out["kiL"] = kiL; out["kdL"] = kdL;
  out["kpR"]  = kpR; out["kiR"] = kiR; out["kdR"] = kdR;
  out["ffAL"] = ffA_L; out["ffBL"] = ffB_L;
  out["ffAR"] = ffA_R; out["ffBR"] = ffB_R;
  serializeJson(out, Serial);
  Serial.println();
}

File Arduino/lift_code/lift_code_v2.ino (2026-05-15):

/*
 * esp32_lift_tof.ino
 * VL53L0X (x5) + DC motor lift + limit switches
 * Serial JSON bridge for ROS2 integration
 * Board: Waveshare ESP32-S3-Zero
 * Protocol: Newline-delimited JSON (NDJSON)
 */

#include <Wire.h>
#include <Adafruit_VL53L0X.h>
#include <ArduinoJson.h>

// ============================================================
//  CONFIGURACIÓN
// ============================================================

#define PIN_SDA 7
#define PIN_SCL 6

#define XSHUT_1 5
#define XSHUT_2 13
#define XSHUT_3 12
#define XSHUT_4 11
#define XSHUT_5 10

#define ADDR_1 0x30
#define ADDR_2 0x31
#define ADDR_3 0x32
#define ADDR_4 0x33
#define ADDR_5 0x34

const char* SENSOR_NAMES[5] = {
  "sensor_1", "sensor_2", "sensor_3", "sensor_4", "sensor_5"
};

// --- Motor DC ---
#define PIN_MOTOR_A  2
#define PIN_MOTOR_B  1
#define MOTOR_SPEED  200   // 0-255

// --- Fines de carrera (pull-down: 10k a GND, switch a 3.3V) ---
#define PIN_LIMIT_TOP    8
#define PIN_LIMIT_BOTTOM 9
#define LIMIT_TRIGGERED  HIGH

// --- Intervalo de publicación sensores ---
#define SENSOR_PUBLISH_INTERVAL_MS 200

// ============================================================
//  VARIABLES GLOBALES
// ============================================================

const uint8_t SENSOR_ADDRS[5] = { ADDR_1, ADDR_2, ADDR_3, ADDR_4, ADDR_5 };
const uint8_t XSHUT_PINS[5]   = { XSHUT_1, XSHUT_2, XSHUT_3, XSHUT_4, XSHUT_5 };

Adafruit_VL53L0X tof[5];

bool lift_running = false;
int  lift_dir     = 0;   // +1 up, -1 down, 0 stop

unsigned long last_publish_ms = 0;

// ============================================================
//  1. HELPERS JSON  (van primero — los usan las demás funciones)
// ============================================================

void publish_error(const char* code, const char* msg) {
  StaticJsonDocument<128> doc;
  doc["type"]    = "error";
  doc["code"]    = code;
  doc["message"] = msg;
  serializeJson(doc, Serial);
  Serial.println();
}

void publish_status(const char* msg) {
  StaticJsonDocument<128> doc;
  doc["type"]    = "status";
  doc["message"] = msg;
  serializeJson(doc, Serial);
  Serial.println();
}

// ============================================================
//  2. MOTOR
// ============================================================

void motor_up() {
  analogWrite(PIN_MOTOR_A, 0);
  analogWrite(PIN_MOTOR_B, MOTOR_SPEED);
}

void motor_down() {
  analogWrite(PIN_MOTOR_A, MOTOR_SPEED);
  analogWrite(PIN_MOTOR_B, 0);
}

void motor_stop() {
  analogWrite(PIN_MOTOR_A, 0);
  analogWrite(PIN_MOTOR_B, 0);
}

// ============================================================
//  3. FINES DE CARRERA
// ============================================================

bool limit_triggered(uint8_t pin) {
  return digitalRead(pin) == LIMIT_TRIGGERED;
}

void check_limits() {
  if (!lift_running) return;

  if (lift_dir == 1 && limit_triggered(PIN_LIMIT_TOP)) {
    motor_stop();
    lift_running = false;
    lift_dir     = 0;
    publish_status("limit_switch_triggered: TOP - lift stopped");
  }
  else if (lift_dir == -1 && limit_triggered(PIN_LIMIT_BOTTOM)) {
    motor_stop();
    lift_running = false;
    lift_dir     = 0;
    publish_status("limit_switch_triggered: BOTTOM - lift stopped");
  }
}

// ============================================================
//  4. SETUP
// ============================================================

void setup() {
  Serial.begin(115200);
  Wire.begin(PIN_SDA, PIN_SCL);

  // Motor
  pinMode(PIN_MOTOR_A, OUTPUT);
  pinMode(PIN_MOTOR_B, OUTPUT);
  motor_stop();

  // Fines de carrera
  pinMode(PIN_LIMIT_TOP,    INPUT);
  pinMode(PIN_LIMIT_BOTTOM, INPUT);

  if (limit_triggered(PIN_LIMIT_TOP))
    publish_status("WARNING: top limit activo al arrancar");
  if (limit_triggered(PIN_LIMIT_BOTTOM))
    publish_status("WARNING: bottom limit activo al arrancar");

  // ToF sensors
  for (int i = 0; i < 5; i++) {
    pinMode(XSHUT_PINS[i], OUTPUT);
    digitalWrite(XSHUT_PINS[i], LOW);
  }
  delay(10);

  for (int i = 0; i < 5; i++) {
    digitalWrite(XSHUT_PINS[i], HIGH);
    delay(10);
    if (!tof[i].begin(SENSOR_ADDRS[i])) {
      char msg[48];
      snprintf(msg, sizeof(msg), "Failed to init %s", SENSOR_NAMES[i]);
      publish_error("TOF_INIT_FAIL", msg);
    } else {
      char msg[48];
      snprintf(msg, sizeof(msg), "%s ready at 0x%02X", SENSOR_NAMES[i], SENSOR_ADDRS[i]);
      publish_status(msg);
    }
  }

  publish_status("esp32_lift_tof ready");
}

// ============================================================
//  5. SERIAL COMMAND HANDLER (ROS2)
// ============================================================

/*
 * Comandos JSON desde ROS2:
 *   {"cmd":"lift","action":"up"}
 *   {"cmd":"lift","action":"down"}
 *   {"cmd":"lift","action":"stop"}
 *   {"cmd":"config","sensor_index":0,"name":"front"}
 */
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

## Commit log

2026-01-26 Revise README for TurtleBot Burger project
    Expanded README to include detailed project goals, bill of materials, key features, known issues, build steps, and contributing guidelines.
2026-01-26 Archivos 3d
    [Cuerpo.SLDPRT, Cuerpo.STL, Ensamblaje1.SLDASM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]
2026-03-11 Add AI Coder Guidelines for ESP32 Motor Control
2026-04-22 Arduino Code
2026-04-24 added modelo de recon.Visual
    [model.ncnn.param]
2026-04-29 Add README.md file for CAD project
2026-04-29 Se agrego el cad de la ultima iteracion
    [28BYJ-48_Stepper.SLDPRT, Apoyo_varilla.SLDPRT, Base.SLDPRT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]
2026-05-14 Firmware V3.0 de PCB motores y Scripts calib_lineal
2026-05-15 Agregar lift_test_code a Arduino/lift_code
